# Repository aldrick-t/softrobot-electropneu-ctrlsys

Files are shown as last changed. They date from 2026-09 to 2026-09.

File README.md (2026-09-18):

# softrobot-electropneu-ctrlsys
Control elements for pneumatic actuated soft robots. Including microcontroller controller firmware, controller PCBs, control board use guidelines and more.

## Closed-loop vacuum controller

This PlatformIO firmware regulates a negative-pressure pneumatic circuit with
an ESP32 DevKit V1, a vacuum-pump motor, a solenoid valve, an ADS1115 ADC, and
a 5 V XGZP6847A pressure sensor. It is set up for the installed
`XGZP6847A100KPGPN` variant: its nominal 0.5–4.5 V output represents −100 to
+100 kPa gauge pressure. The controller only commands negative pressure.

### Hardware and signal path

| Function | Connection | Firmware behavior |
| --- | --- | --- |
| Pump motor PWM | ESP32 GPIO 2 | `0` is off; `255` is full duty cycle. |
| Solenoid valve | ESP32 GPIO 5 | HIGH opens the pump-to-gripper path; LOW de-energizes the valve and vents the gripper. |
| Target-reached LED1 (green) | ESP32 GPIO 12 through 220 Ω to GND | On only when serial closed-loop pressure is within the configured deadband. |
| Active LED2 | ESP32 GPIO 13 through 220 Ω to GND | On when firmware commands nonzero pump PWM or energizes the valve. |
| Mode switch: manual full | ESP32 GPIO 26 with 1 kΩ pulldown | 3.3 V selects pump PWM `255` and valve open. |
| Mode switch: serial control | ESP32 GPIO 27 with 1 kΩ pulldown | 3.3 V enables serial closed-loop control. |
| ADS1115 SDA | ESP32 GPIO 21 through the 3.3 V/5 V I2C level shifter | Initialized with `Wire.begin(21, 22)`. |
| ADS1115 SCL | ESP32 GPIO 22 through the 3.3 V/5 V I2C level shifter | Initialized with `Wire.begin(21, 22)`. |
| XGZP6847A output | ADS1115 A0 | Read as a 5 V-domain analog signal; it never connects directly to the ESP32. |

The ADC uses its ±6.144 V range (`GAIN_TWOTHIRDS`), so the sensor's 0.5–4.5 V
signal cannot clip. After field zeroing, the nominal conversion is:

```text
pressure_kPa = 50 × (sensor_volts − zero_volts)
```

`ZERO` removes the atmospheric offset; it does not replace a calibrated span
check against a reference gauge.

## Operation

With the pressure port open to atmosphere, first send:

```text
ZERO
```

The controller turns both outputs off for one second, then averages 32 stable
pressure samples. Do not obstruct the vent or run the pump while it calibrates.

After `ZERO complete`, send a negative gauge-pressure target as a bare number:

```text
-20
-65.93
```

The accepted range is −90 to 0 kPa. Values below −90 kPa clamp to −90; positive
values clamp to zero and vent. Any zero representation stops control and vents:

```text
0
0.0
-0.0
```

### Serial commands

| Command | Effect |
| --- | --- |
| `ZERO` | In serial mode, vent, establish atmospheric offset, and permit negative targets. Required after every reboot. |
| `STATUS` | Print controller state, mode, voltage, pressure, target, PWM, valve state, LED states, ADC address, calibration state, and tuning. |
| `STATUS_STREAM` | Toggle continuous `STATUS` output at 20 Hz. Send `STATUS_STREAM` again to stop it. |
| `KP <value>` | Set proportional gain in RAM; allowed range 0–50. |
| `KI <value>` | Set integral gain in RAM; allowed range 0–20. |
| `KD <value>` | Set derivative damping gain in RAM; allowed range 0–10. |
| `BAND <kPa>` | Set deadband in RAM; allowed range 0.1–5 kPa. |
| `SAVE` | Persist current validated tuning in ESP32 Preferences. |
| `DEFAULTS` | Restore conservative default tuning in RAM; send `SAVE` to retain it after reboot. |

Malformed commands stop active control and vent as a precaution.

## Controller behavior

The loop runs every 50 ms and averages four ADS1115 readings per update. PID
control uses anti-windup, a filtered pressure-rate term, and a PWM slew limit.

- If pressure is not negative enough, the valve opens to the pump and PWM rises
  gradually.
- At or beyond the target deadband, the pump turns off while the valve remains
  on the pump-to-gripper path. The controller does not use the full-flow
  atmosphere vent as a corrective actuator.
- Passive venting (valve off) remains the safety/release path for `0`, faults,
  malformed commands, and `ZERO`.

This checkout's defaults are `KP=18`, `KI=1`, `KD=0.3`, and `BAND=0.5 kPa`.
Tune them on the real pump, tubing volume, valve flow, and gripper before
relying on them. In particular, confirm that valve-on/pump-off holds vacuum
without overheating a non-continuous-duty valve coil.

### Switch modes and LEDs

The SPDT mode switch is the output authority. The firmware reads both switch
inputs on every loop and accepts only these complementary states:

| GPIO 26 | GPIO 27 | Mode | Output behavior |
| --- | --- | --- | --- |
| HIGH | LOW | Manual full-drive | Pump PWM is `255` and the valve is energized, even if the ADS1115 is unavailable or faulted. Entering this mode cancels any serial target or calibration in progress. LED2 is on; LED1 is off. |
| LOW | HIGH | Serial closed-loop | The controller remains vented/idle until a new negative serial target is sent. Existing ADC, `ZERO`, target-range, and fault checks apply. |
| LOW | LOW | Safe off | Pump and valve are de-energized. |
| HIGH | HIGH | Safe off | Pump and valve are de-energized. |

Returning from manual full-drive to serial mode does not restore an earlier
target; send `ZERO` if needed, then a new negative target. In manual or
safe-off mode, `ZERO` and numeric target commands are rejected. `STATUS`,
tuning commands, `SAVE`, and `DEFAULTS` remain available.

LED1 is off while the controller ramps, vents, settles, calibrates, idles, is
faulted, or is in manual/safe-off mode. LED2 represents **commanded drive**:
it cannot prove that a disconnected, stalled, or failed motor/valve is drawing
current because this board has no current-sense circuit.

### ADS1115 ADDR override

For reliable normal operation, wire ADS1115 `ADDR` to GND and use I2C address
`0x48`. The ADS1115 samples this address-selection pin continuously, so a
floating pin is not dependable.

For initial bench testing, `src/main.cpp` includes:

```cpp
const bool ALLOW_FLOATING_ADS1115_ADDR_FOR_TESTING = true;
```

With this temporary toggle enabled, firmware first tries `0x48`, then the
other legal ADS1115 addresses (`0x49`, `0x4A`, `0x4B`). It prints a warning if
the ADC is found away from `0x48`; `STATUS` also reports `ADS_ADDR`. This only
accommodates an accidentally stable floating pin. After wiring `ADDR → GND`,
set this toggle to `false` and rebuild.

## Installation and upload

1. Install [PlatformIO for VS Code](https://platformio.org/install/ide?install=vscode)
   and open this repository as a PlatformIO project.
2. Confirm `platformio.ini` targets `esp32doit-devkit-v1`.
3. Build. PlatformIO installs `Adafruit ADS1X15` automatically; `Arduino`,
   `Wire`, and ESP32 `Preferences` are framework libraries.

   ```sh
   pio run
   ```

4. Connect the ESP32 by USB and upload:

   ```sh
   pio run --target upload
   ```

5. Open a serial monitor at **115200 baud** with line ending set to `Newline`:

   ```sh
   pio device monitor --baud 115200
   ```

Boot starts deliberately uncalibrated. The firmware leaves the pump and valve
off and rejects negative targets until `ZERO` succeeds.

## Idle, off, and fault behavior

The firmware commands **both motor and valve off electrically** when it
is idle or at atmospheric pressure:

```cpp
setOutputs(PWM_OFF, false);
// pump:  analogWrite(GPIO 2, 0)
// valve: analogWrite(GPIO 5, 0)
```

This output path is used at boot, after `0`, after a positive target clamps to
zero, after malformed input, during zeroing, on pressure/ADC faults, and for
invalid mode-switch states. The D26 manual-full mode is the explicit exception:
it deliberately drives both outputs even with a sensor fault. With the stated
plumbing, valve-off is also the pneumatic vent state; it does not attempt to
hold vacuum. Therefore the valve coil is not intentionally kept energized while
idle, avoiding prolonged activation and overheating.

This conclusion assumes a non-inverting valve driver where GPIO 5 HIGH
energizes the coil, as defined by the original controller. Confirm that once
with a multimeter or indicator LED before connecting a gripper.

## First physical test

1. Test with the gripper disconnected or a conservative vented fixture.
2. Select serial mode (GPIO 27 HIGH) and send `STATUS`; verify `MODE=SERIAL`,
   `PWM=0`, `VALVE=VENT`, `LED1=OFF`, `LED2=OFF`, and `ZERO=REQUIRED`.
3. Run `ZERO` with the port open to atmosphere. If possible, compare reported
   voltage with a multimeter at ADS1115 A0.
4. Start with `-5`, then `-10`; verify motor PWM ramps rather than jumps,
   LED2 is on while the pump or valve is commanded, and LED1 turns on only
   after pressure reaches the configured deadband.
5. Send `0` and verify both PWM outputs and both LEDs are off before longer tests.
6. Select manual full-drive (GPIO 26 HIGH) and verify `PWM=255`, `VALVE=OPEN`,
   LED2 on, and LED1 off. Return to serial mode and verify it remains vented
   until a new negative target is sent.
7. Verify both-low and both-high switch input states keep both outputs and LEDs off.
8. Tune one variable at a time and send `SAVE` only after physical validation.

Never treat the −90 kPa software clamp as proof that the gripper, tubing,
fittings, or pump are safe at that pressure.

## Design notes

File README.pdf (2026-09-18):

# softrobot-electropneu-ctrlsys

Control elements for pneumatic actuated soft robots. Including microcontroller controller firmware, controller PCBs, control board use guidelines and more.

## Closed-loop vacuum controller

This PlatformIO firmware regulates a negative-pressure pneumatic circuit with an ESP32 DevKit V1, a vacuum-pump motor, a solenoid valve, an ADS1115 ADC, and a 5 V XGZP6847A pressure sensor. It is set up for the installed XGZP6847A100KPGPN variant: its nominal 0.5–4.5 V output represents −100 to +100 kPa gauge pressure. The controller only commands negative pressure.

Hardware and signal path

Function | Connection | Firmware behavior
Pump motor PWM | ESP32 GPIO 2 | 0 is off; 255 is full duty cycle.
Solenoid valve | ESP32 GPIO 5 | HIGH opens the pump-to-gripper path; LOW de-energizes the valve and vents the gripper.
Target-reached LED1 (green) | ESP32 GPIO 12 through 220 Ω to GND | On only when serial closed-loop pressure is within the configured deadband.
Active LED2 | ESP32 GPIO 13 through 220 Ω to GND | On when firmware commands nonzero pump PWM or energizes the valve.
Mode switch: manual full | ESP32 GPIO 26 with 1 kΩ pulldown | 3.3 V selects pump PWM 255 and valve open.
Mode switch: serial control | ESP32 GPIO 27 with 1 kΩ pulldown | 3.3 V enables serial closed-loop control.

ADS1115 SDA

ESP32 GPIO 21 through the
3.3 V/5 V I2C level shifter

Initialized with Wire.begin(21, 22).

ADS1115 SCL

ESP32 GPIO 22 through the
3.3 V/5 V I2C level shifter

Initialized with Wire.begin(21, 22).

XGZP6847A
output

ADS1115 A0

Read as a 5 V-domain analog signal; it never connects directly to the ESP32.

The ADC uses its ±6.144 V range (GAIN_TWOTHIRDS), so the sensor's 0.5–4.5 V signal cannot clip. After field zeroing, the nominal conversion is:

pressure_kPa = 50 × (sensor_volts − zero_volts)

ZERO removes the atmospheric offset; it does not replace a calibrated span check against a reference gauge.

README.md | 2026-09-18

ADS1115 ADDR: temporary test override

For reliable normal operation, wire ADS1115 ADDR to GND and use I2C address 0x48. The ADS1115 samples this address-selection pin continuously, so a floating pin is not dependable.

For initial bench testing, src/main.cpp includes:

With this temporary toggle enabled, firmware first tries 0x48, then the other legal ADS1115 addresses (0x49, 0x4A, 0x4B). It prints a warning if the ADC is found away from 0x48; STATUS also reports ADS_ADDR. This only accommodates an accidentally stable floating pin. After wiring ADDR → GND, set this toggle to false and rebuild.

## Installation and upload

1. Install PlatformIO for VS Code (https://platformio.org/install/ide?install=vscode) and open this repository as a PlatformIO project.
2. Confirm platformio.ini targets esp32doit-devkit-v1.
3. Build. PlatformIO installs Adafruit ADS1X15 automatically; Arduino, Wire, and ESP32
4. Connect the ESP32 by USB and upload:
5. Open a serial monitor at 115200 baud with line ending set to Newline:

Boot starts deliberately uncalibrated. The firmware leaves the pump and valve off and rejects negative targets until ZERO succeeds.

Switch modes and LEDs

The SPDT mode switch is the output authority. The firmware reads both switch inputs on every loop and accepts only these complementary states:

GPIO
26

GPIO
27
Mode | Output behavior
HIGH | LOW

Manual
full-drive

Pump PWM is 255 and the valve is energized, even if the ADS1115 is unavailable or faulted. Entering this mode cancels any serial target or calibration in progress. LED2 is on; LED1 is off.

LOW | HIGH | Serial closed- loop | The controller remains vented/idle until a new negative serial target is sent. Existing ADC, ZERO, target-range, and fault checks apply.
LOW | LOW | Safe off | Pump and valve are de-energized.
HIGH | HIGH | Safe off | Pump and valve are de-energized.

Returning from manual full-drive to serial mode does not restore an earlier target; send ZERO if needed, then a new negative target. In manual or safe-off mode, ZERO and numeric target commands are rejected. STATUS, tuning commands, SAVE, and DEFAULTS remain available.

LED1 is off while the controller ramps, vents, settles, calibrates, idles, is faulted, or is in manual/safe-off mode. LED2 represents commanded drive: it cannot prove that a disconnected, stalled, or failed motor/valve is drawing current because this board has no current-sense circuit.

## Operation

With the pressure port open to atmosphere, first send:

The controller turns both outputs off for one second, then averages 32 stable pressure samples. Do not obstruct the vent or run the pump while it calibrates.

After ZERO complete, send a negative gauge-pressure target as a bare number:

The accepted range is −90 to 0 kPa. Values below −90 kPa clamp to −90; positive values clamp to zero and vent. Any zero representation stops control and vents:

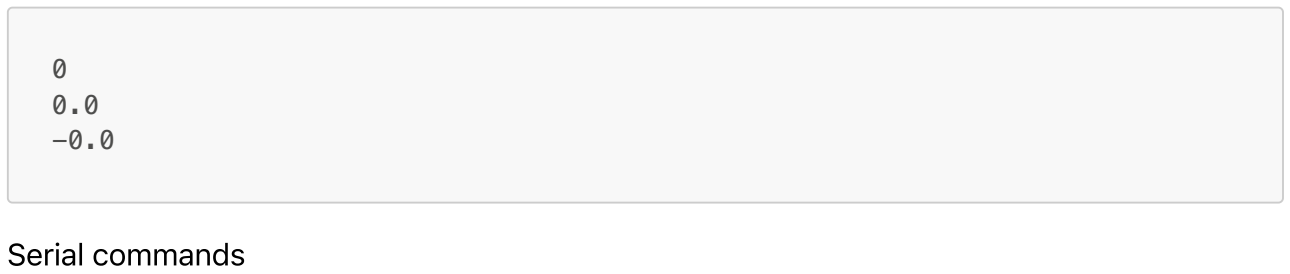
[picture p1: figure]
Serial commands

Command | Effect
ZERO | In serial mode, vent, establish atmospheric offset, and permit negative targets. Required after every reboot.
STATUS | Print controller state, mode, voltage, pressure, target, PWM, valve state, LED states, ADC address, calibration state, and tuning.
STATUS_STREAM | Toggle continuous STATUS output at 20 Hz. Send STATUS_STREAM again to stop it.
KP <value> | Set proportional gain in RAM; allowed range 0–50.
KI <value> | Set integral gain in RAM; allowed range 0–20.
KD <value> | Set derivative damping gain in RAM; allowed range 0–10.
BAND <kPa> | Set deadband in RAM; allowed range 0.1–5 kPa.
SAVE | Persist current validated tuning in ESP32 Preferences.
DEFAULTS | Restore conservative default tuning in RAM; send SAVE to retain it after reboot.

Malformed commands stop active control and vent as a precaution.

## Controller behavior

The loop runs every 50 ms and averages four ADS1115 readings per update. PID control uses antiwindup, a filtered pressure-rate term, and a PWM slew limit.

If pressure is not negative enough, the valve opens to the pump and PWM rises gradually.
At or beyond the target deadband, the pump turns off while the valve remains on the pump-togripper path. The controller does not use the full-flow atmosphere vent as a corrective actuator. Passive venting (valve off) remains the safety/release path for 0, faults, malformed commands, and ZERO.

This checkout's defaults are KP=18, KI=1, KD=0.3, and BAND=0.5 kPa. Tune them on the real pump, tubing volume, valve flow, and gripper before relying on them. In particular, confirm that valve-on/pumpoff holds vacuum without overheating a non-continuous-duty valve coil.

## Idle, off, and fault behavior

Yes: the firmware commands both motor and valve off electrically when it is idle or at atmospheric

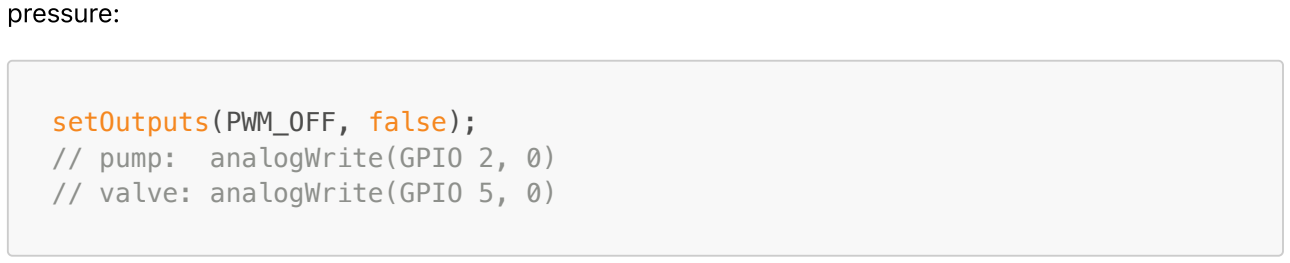
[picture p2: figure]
pressure:; setOutputs(PWM_OFF, false); // pump: analogWrite(GPIO 2, 0) // valve: analogWrite(GPIO 5, 0)

This output path is used at boot, after 0, after a positive target clamps to zero, after malformed input, during zeroing, on pressure/ADC faults, and for invalid mode-switch states. The D26 manual-full mode is the explicit exception: it deliberately drives both outputs even with a sensor fault. With the stated plumbing, valve-off is also the pneumatic vent state; it does not attempt to hold vacuum. Therefore the valve coil is not intentionally kept energized while idle, avoiding prolonged activation and overheating.

This conclusion assumes a non-inverting valve driver where GPIO 5 HIGH energizes the coil, as defined by the original controller. Confirm that once with a multimeter or indicator LED before connecting a gripper.

## First physical test

1. Test with the gripper disconnected or a conservative vented fixture.
2. Select serial mode (GPIO 27 HIGH) and send STATUS; verify MODE=SERIAL, PWM=0, VALVE=VENT, LED1=OFF, LED2=OFF, and ZERO=REQUIRED.
3. Run ZERO with the port open to atmosphere. If possible, compare reported voltage with a multimeter at ADS1115 A0.
4. Start with -5, then -10; verify motor PWM ramps rather than jumps, LED2 is on while the pump or valve is commanded, and LED1 turns on only after pressure reaches the configured deadband.
5. Send 0 and verify both PWM outputs and both LEDs are off before longer tests.
6. Select manual full-drive (GPIO 26 HIGH) and verify PWM=255, VALVE=OPEN, LED2 on, and LED1 off. Return to serial mode and verify it remains vented until a new negative target is sent.
7. Verify both-low and both-high switch input states keep both outputs and LEDs off.
8. Tune one variable at a time and send SAVE only after physical validation.

Never treat the −90 kPa software clamp as proof that the gripper, tubing, fittings, or pump are safe at that pressure.

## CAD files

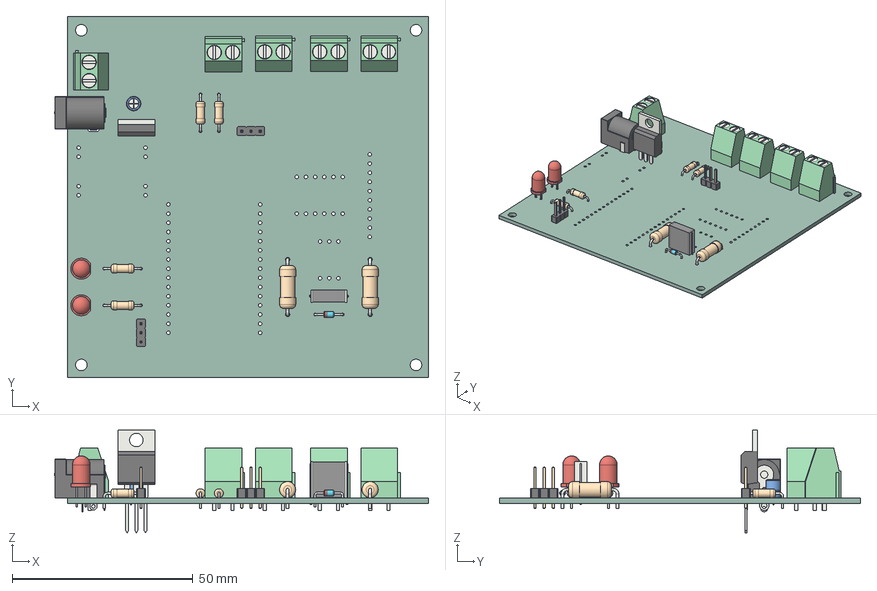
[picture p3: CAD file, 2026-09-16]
electropneu/electropneu.step
103.6 x 100.0 x 28.5 mm
LED_D5.0mm x 2
TerminalBlock_Phoenix_MKDS-1,5-2-5.08_1x02_P5.08mm_Horizontal x 5
C_Radial_D4.0mm_H5.0mm_P1.50mm
R_Axial_DIN0414_L11.9mm_D4.5mm_P15.24mm_Horizontal x 2
D_DO-34_SOD68_P7.62mm_Horizontal
BarrelJack_Horizontal
PinHeader_1x03_P2.54mm_Vertical x 2
TO-220-3_Vertical
R_Axial_DIN0207_L6.3mm_D2.5mm_P10.16mm_Horizontal x 4
C_Rect_L11.0mm_W3.4mm_P10.00mm_MKT
electropneu_PCB

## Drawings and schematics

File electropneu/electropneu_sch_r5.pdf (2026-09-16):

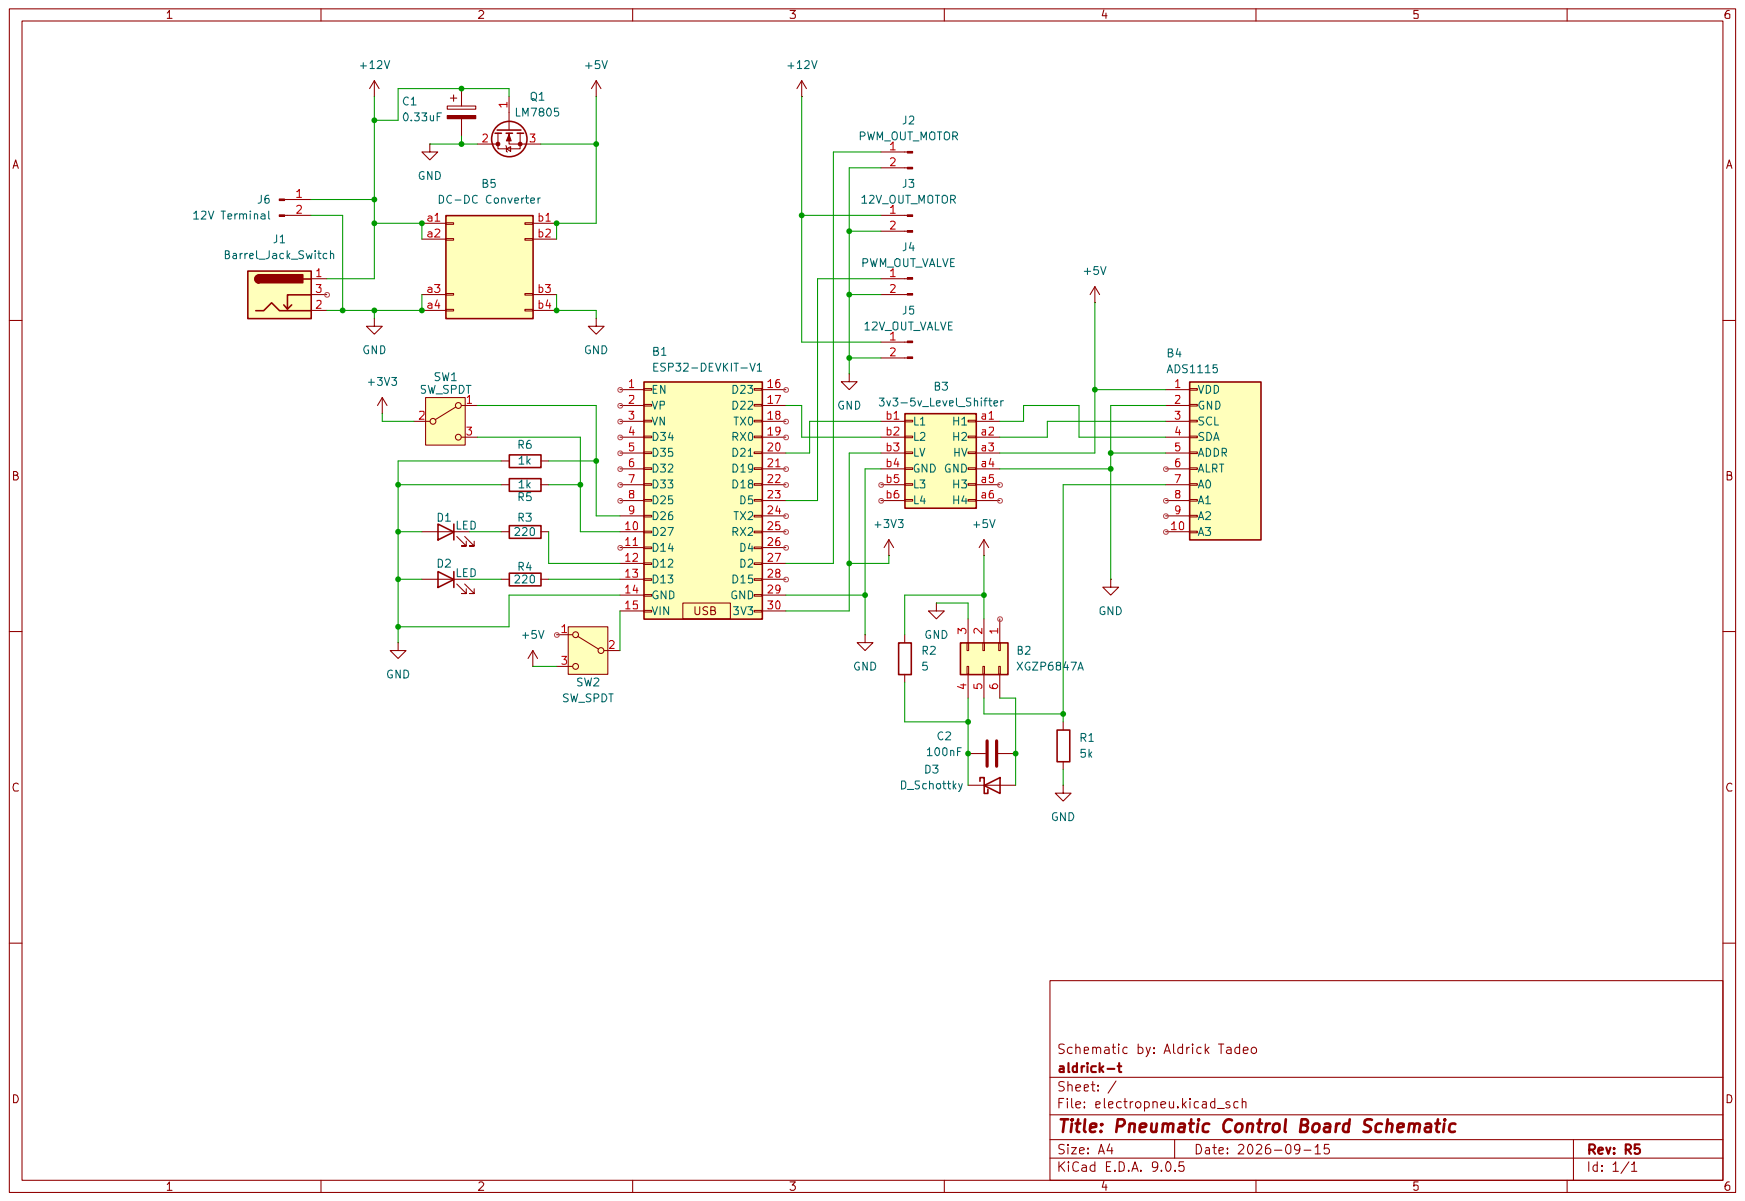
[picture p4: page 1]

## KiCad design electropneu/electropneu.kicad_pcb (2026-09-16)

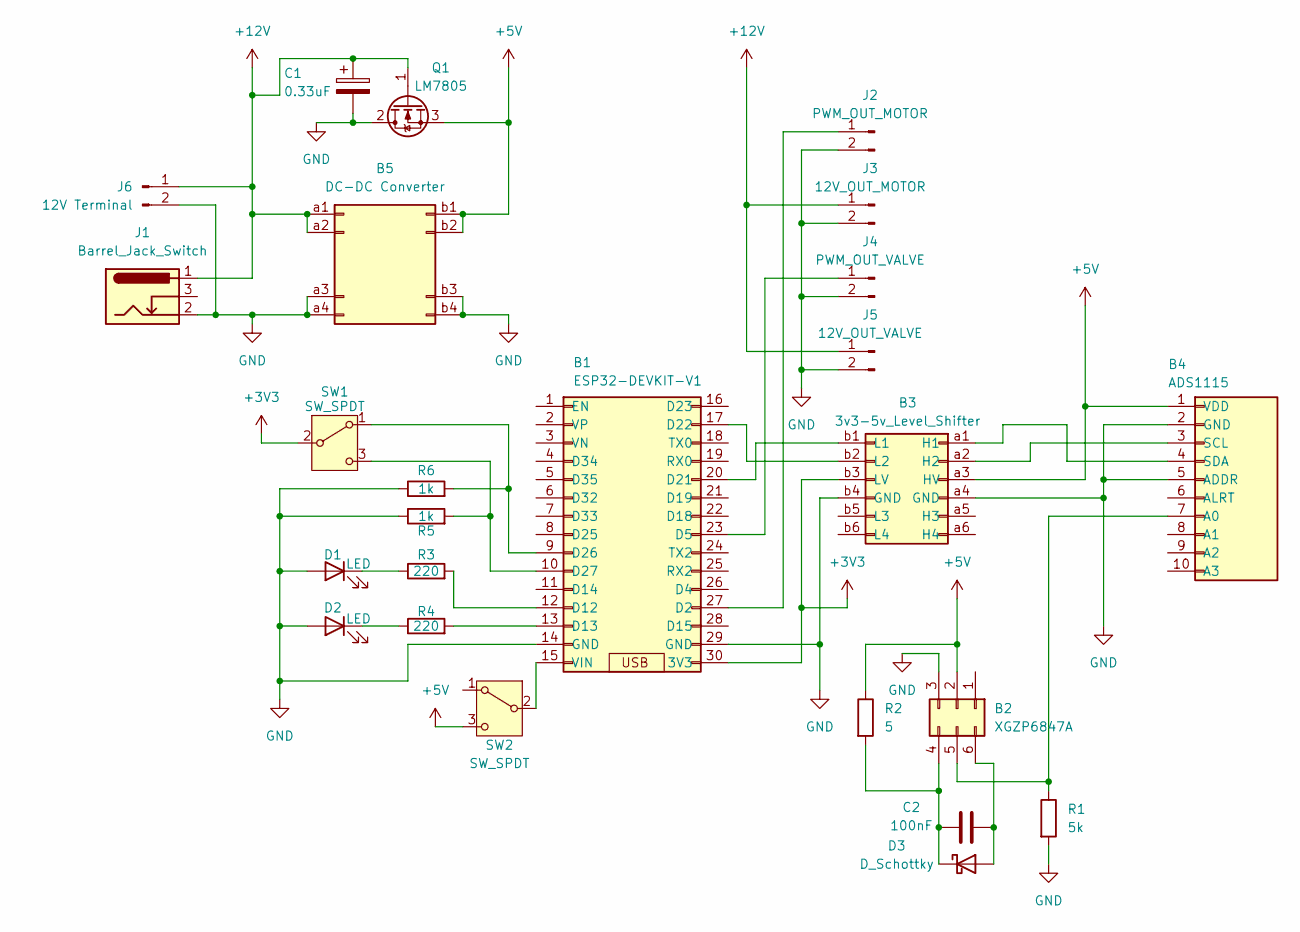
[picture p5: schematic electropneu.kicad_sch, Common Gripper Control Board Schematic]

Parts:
B1: ESP32-DEVKIT-V1
B2: XGZP6847A; XGZP6847A Sensor Board
B3: 3v3-5v_Level_Shifter; LevelShifter_3V3-5V
B4: ADS1115; ADS1115 Board
B5: DC-DC Converter; MP1584EN Board
C1: 0.33uF; C_Radial_D4.0mm_H5.0mm_P1.50mm
C2: 100nF; C_Rect_L11.0mm_W3.4mm_P10.00mm_MKT
D1, D2: LED; LED_D5.0mm
D3: D_Schottky; D_DO-34_SOD68_P7.62mm_Horizontal
J1: Barrel_Jack_Switch; BarrelJack_Horizontal
J2: PWM_OUT_MOTOR; TerminalBlock_Phoenix_MKDS-1,5-2-5.08_1x02_P5.08mm_Horizont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
J3: 12V_OUT_MOTOR; TerminalBlock_Phoenix_MKDS-1,5-2-5.08_1x02_P5.08mm_Horizont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
J4: PWM_OUT_VALVE; TerminalBlock_Phoenix_MKDS-1,5-2-5.08_1x02_P5.08mm_Horizont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
J5: 12V_OUT_VALVE; TerminalBlock_Phoenix_MKDS-1,5-2-5.08_1x02_P5.08mm_Horizont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
J6: 12V Terminal; TerminalBlock_Phoenix_MKDS-1,5-2-5.08_1x02_P5.08mm_Horizont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
Q1: LM7805; TO-220-3_Vertical
R1: 5k; R_Axial_DIN0414_L11.9mm_D4.5mm_P15.24mm_Horizontal
R2: 5; R_Axial_DIN0414_L11.9mm_D4.5mm_P15.24mm_Horizontal
R3, R4: 220; R_Axial_DIN0207_L6.3mm_D2.5mm_P10.16mm_Horizontal
R5, R6: 1k; R_Axial_DIN0207_L6.3mm_D2.5mm_P10.16mm_Horizontal
SW1, SW2: SW_SPDT; PinHeader_1x03_P2.54mm_Vertical

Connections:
+3V3: B1.30 (3V3), B3.b3 (LV), SW1.2 (B)
+5V: B2.2, B3.a3 (HV), B4.1 (VDD), B5.b1, B5.b2, Q1.3 (S), R2.1, SW2.3 (C)
+12V: B5.a1, B5.a2, C1.1, J1.1, J3.1, J5.1, J6.1, Q1.1 (G)
GND: B1.14 (GND), B1.29 (GND), B2.3, B3.a4 (GND), B3.b4 (GND), B4.2 (GND), B4.5 (ADDR), B5.a3, B5.a4, B5.b3, B5.b4, C1.2, D1.2 (A), D2.2 (A), J1.2, J2.2, J3.2, J4.2, J5.2, J6.2, Q1.2 (D), R1.2, R5.1, R6.1
unnamed: B1.27 (D2), J2.1
unnamed: B1.23 (D5), J4.1
unnamed: B1.12 (D12), R3.2
unnamed: B1.13 (D13), R4.2
unnamed: B1.20 (D21), B3.b1 (L1)
unnamed: B1.17 (D22), B3.b2 (L2)
unnamed: B1.9 (D26), R6.2, SW1.1 (A)
unnamed: B1.10 (D27), R5.2, SW1.3 (C)
unnamed: B1.15 (VIN), SW2.2 (B)
unnamed: B2.4, C2.1, D3.1 (K), R2.2
unnamed: B2.5, B4.7 (A0), R1.1
unnamed: B2.6, C2.2, D3.2 (A)
unnamed: B3.a1 (H1), B4.4 (SDA)
unnamed: B3.a2 (H2), B4.3 (SCL)
unnamed: D1.1 (K), R3.1
unnamed: D2.1 (K), R4.1

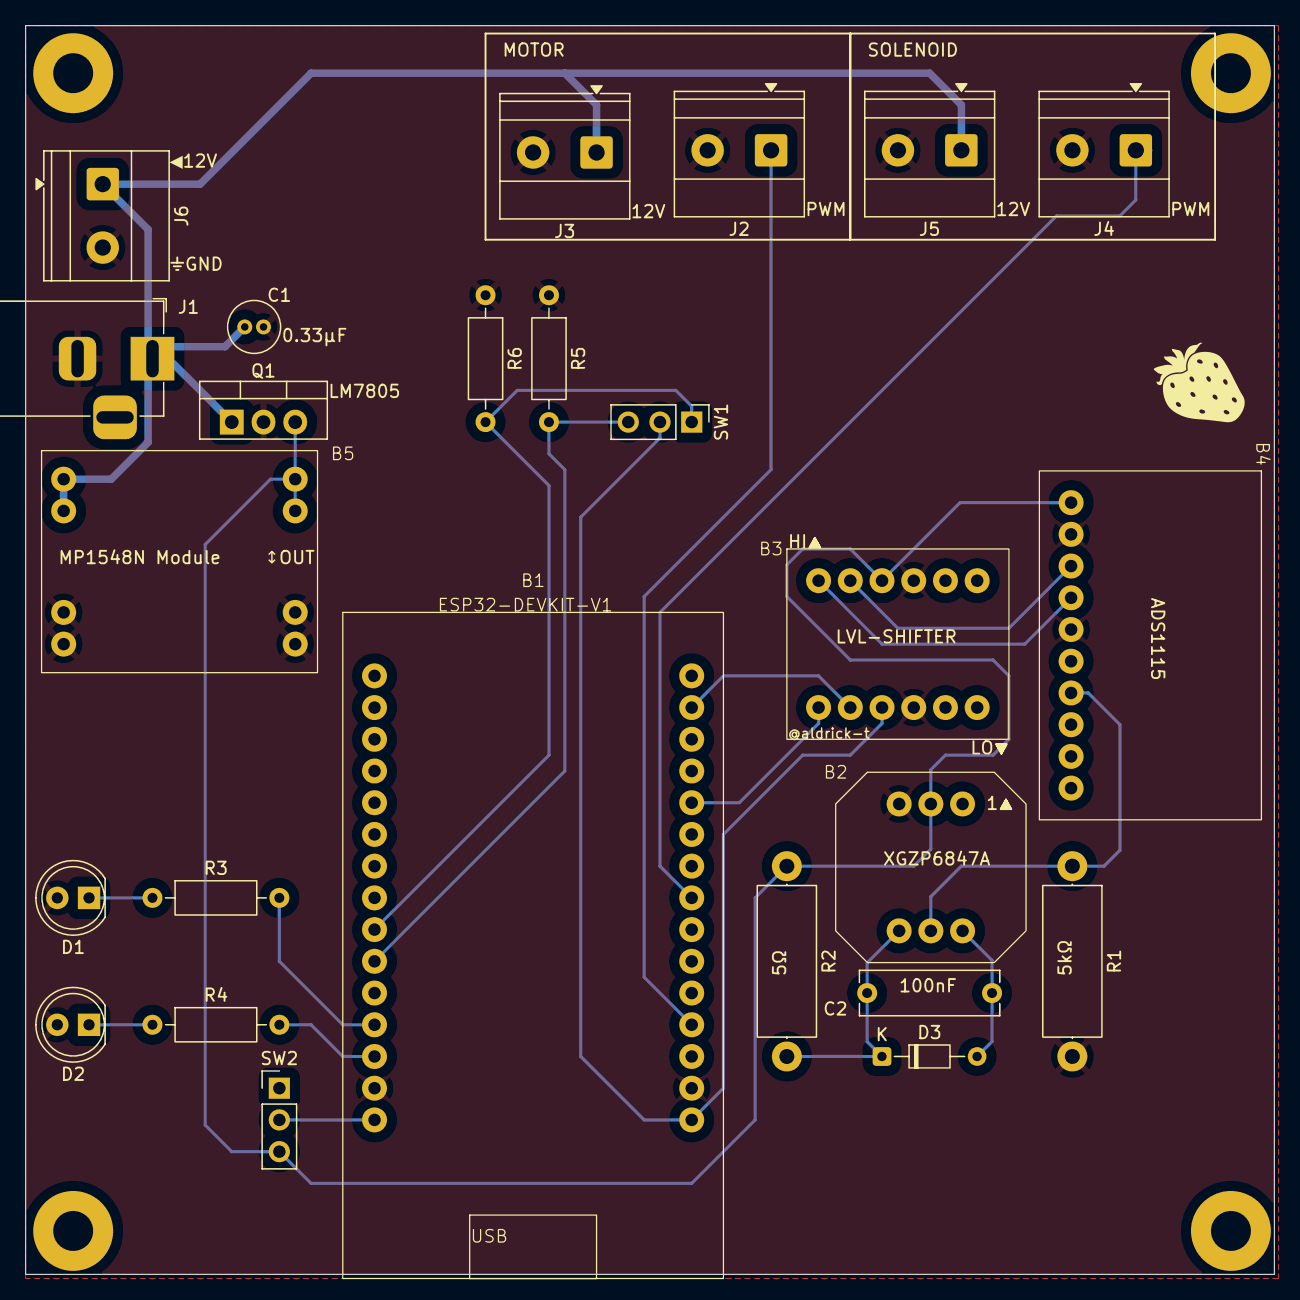
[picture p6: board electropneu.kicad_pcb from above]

Board: 2 copper layers, 100.0 x 100.0 mm, 25 parts (0 on the bottom side), 20 nets.

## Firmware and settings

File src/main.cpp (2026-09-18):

#include <Arduino.h>
#include <Adafruit_ADS1X15.h>
#include <Preferences.h>
#include <Wire.h>

#include <math.h>
#include <stdlib.h>
#include <string.h>

// Board connections retained from the original on/off controller.
const uint8_t PIN_PWM_PUMP = 2;
const uint8_t PIN_PWM_VALVE = 5;
const uint8_t PIN_LED_TARGET_REACHED = 12;
const uint8_t PIN_LED_ACTIVE = 13;
const uint8_t PIN_I2C_SDA = 21;
const uint8_t PIN_I2C_SCL = 22;
const uint8_t PIN_SWITCH_MANUAL_FULL = 26;
const uint8_t PIN_SWITCH_SERIAL = 27;

const uint8_t ADS1115_GND_ADDRESS = 0x48;
// Temporary bench-test override only. When true, the firmware falls back to the
// other legal ADS1115 addresses if a floating ADDR pin does not answer at 0x48.
// Set false after wiring ADDR to GND for normal operation.
const bool ALLOW_FLOATING_ADS1115_ADDR_FOR_TESTING = true;
const uint8_t ADS1115_CHANNEL = 0;

const uint32_t CONTROL_PERIOD_MS = 50;
const uint32_t STATUS_STREAM_PERIOD_MS = CONTROL_PERIOD_MS;
const uint32_t ZERO_SETTLE_MS = 1000;
const uint8_t ZERO_SAMPLE_COUNT = 32;
const uint8_t ADC_AVERAGE_COUNT = 4;
const float ZERO_MAX_STDDEV_KPA = 0.10f;

const float SENSOR_KPA_PER_VOLT = 50.0f;  // 100KPGPN: -100..100 kPa over 0.5..4.5 V.
const float MAX_VACUUM_TARGET_KPA = -90.0f;
const float ADC_MIN_VALID_VOLTS = 0.25f;
const float ADC_MAX_VALID_VOLTS = 4.75f;
const uint8_t MAX_INVALID_READINGS = 3;

const uint8_t PWM_OFF = 0;
const uint8_t PWM_MAX = 255;
const uint8_t PWM_SLEW_PER_CYCLE = 10;
const float DERIVATIVE_FILTER_ALPHA = 0.25f;

struct Tuning {
  float kp;
  float ki;
  float kd;
  float bandKpa;
};

const Tuning DEFAULT_TUNING = {6.0f, 0.0f, 0.6f, 1.0f};
const char *PREFERENCES_NAMESPACE = "vacuum-ctl";

enum class ControllerState {
  IDLE,
  CALIBRATING_SETTLE,
  CALIBRATING_SAMPLE,
  REGULATING,
  FAULT,
};

enum class ControlMode {
  SAFE_OFF,
  SERIAL_CONTROL,
  MANUAL_FULL,
};

Adafruit_ADS1115 ads;
Preferences preferences;
Tuning tuning = DEFAULT_TUNING;
ControllerState state = ControllerState::IDLE;
ControlMode controlMode = ControlMode::SAFE_OFF;

bool adsAvailable = false;
uint8_t adsAddressInUse = ADS1115_GND_ADDRESS;
bool zeroCalibrated = false;
float zeroVolts = NAN;
float measuredVolts = NAN;
float measuredPressureKpa = NAN;
float targetPressureKpa = 0.0f;
float integralTerm = 0.0f;
float previousVacuumKpa = NAN;
float filteredVacuumRate = 0.0f;
uint8_t pumpPwm = PWM_OFF;
bool valveOpen = false;
bool targetLedOn = false;
bool activeLedOn = false;
uint8_t invalidReadings = 0;
uint32_t lastControlMs = 0;
uint32_t phaseStartedMs = 0;
uint32_t lastPidMs = 0;
float zeroSum = 0.0f;
float zeroSumSquared = 0.0f;
uint8_t zeroSamples = 0;

char serialLine[96];
size_t serialLength = 0;
bool statusStreamEnabled = false;
uint32_t lastStatusStreamMs = 0;

const char *stateName(ControllerState currentState) {
  switch (currentState) {
    case ControllerState::IDLE:
      return "IDLE";
    case ControllerState::CALIBRATING_SETTLE:
      return "ZERO_SETTLE";
    case ControllerState::CALIBRATING_SAMPLE:
      return "ZERO_SAMPLE";
    case ControllerState::REGULATING:
      return "REGULATING";
    case ControllerState::FAULT:
      return "FAULT";
  }
  return "UNKNOWN";
}

const char *controlModeName(ControlMode mode) {
  switch (mode) {
    case ControlMode::SAFE_OFF:
      return "SAFE_OFF";
    case ControlMode::SERIAL_CONTROL:
      return "SERIAL";
    case ControlMode::MANUAL_FULL:
      return "MANUAL_FULL";
  }
  return "UNKNOWN";
}

bool isTargetReached() {
  return controlMode == ControlMode::SERIAL_CONTROL && state == ControllerState::REGULATING &&
         zeroCalibrated && isfinite(targetPressureKpa) && targetPressureKpa < 0.0f &&
         isfinite(measuredPressureKpa) &&
         fabsf(measuredPressureKpa - targetPressureKpa) <= tuning.bandKpa;
}

void updateIndicators() {
  targetLedOn = isTargetReached();
  activeLedOn = pumpPwm != PWM_OFF || valveOpen;
  digitalWrite(PIN_LED_TARGET_REACHED, targetLedOn ? HIGH : LOW);
  digitalWrite(PIN_LED_ACTIVE, activeLedOn ? HIGH : LOW);
}

void setOutputs(uint8_t requestedPumpPwm, bool openValve) {
  pumpPwm = requestedPumpPwm;
  valveOpen = openValve;
  analogWrite(PIN_PWM_PUMP, pumpPwm);
  analogWrite(PIN_PWM_VALVE, valveOpen ? PWM_MAX : PWM_OFF);
  updateIndicators();
}

void resetPid() {
  integralTerm = 0.0f;
  previousVacuumKpa = NAN;
  filteredVacuumRate = 0.0f;
  lastPidMs = 0;
}

void cancelSerialControl() {
  targetPressureKpa = 0.0f;
  resetPid();
  zeroSum = 0.0f;
  zeroSumSquared = 0.0f;
  zeroSamples = 0;
  if (state != ControllerState::FAULT) {
    state = ControllerState::IDLE;
  }
  updateIndicators();
}

ControlMode readControlMode() {
  const bool manualFullSelected = digitalRead(PIN_SWITCH_MANUAL_FULL) == HIGH;
  const bool serialSelected = digitalRead(PIN_SWITCH_SERIAL) == HIGH;

  if (manualFullSelected && !serialSelected) {
    return ControlMode::MANUAL_FULL;
  }
  if (!manualFullSelected && serialSelected) {
    return ControlMode::SERIAL_CONTROL;
  }
  return ControlMode::SAFE_OFF;
}

void serviceControlMode() {
  const ControlMode requestedMode = readControlMode();
  if (requestedMode != controlMode) {
    controlMode = requestedMode;
    if (controlMode == ControlMode::MANUAL_FULL || controlMode == ControlMode::SAFE_OFF) {
      cancelSerialControl();
    }

    Serial.print("MODE=");
    Serial.println(controlModeName(controlMode));
  }

  if (controlMode == ControlMode::MANUAL_FULL) {
    setOutputs(PWM_MAX, true);
  } else if (controlMode == ControlMode::SAFE_OFF) {
    setOutputs(PWM_OFF, false);
  }
}

void stopAndVent(const char *message) {
  targetPressureKpa = 0.0f;
  resetPid();
  state = ControllerState::IDLE;
  setOutputs(PWM_OFF, false);
  if (message != nullptr) {
    Serial.println(message);
  }
}

void enterFault(const char *message) {
  targetPressureKpa = 0.0f;
  zeroCalibrated = false;
  resetPid();
  state = ControllerState::FAULT;
  setOutputs(PWM_OFF, false);
  Serial.print("FAULT: ");
  Serial.println(message);
}

bool tuningIsValid(const Tuning &candidate) {
  return isfinite(candidate.kp) && candidate.kp >= 0.0f && candidate.kp <= 50.0f &&
         isfinite(candidate.ki) && candidate.ki >= 0.0f && candidate.ki <= 20.0f &&
         isfinite(candidate.kd) && candidate.kd >= 0.0f && candidate.kd <= 10.0f &&
         isfinite(candidate.bandKpa) && candidate.bandKpa >= 0.1f && candidate.bandKpa <= 5.0f;
}

void loadTuning() {
  Tuning loaded = DEFAULT_TUNING;
  if (preferences.begin(PREFERENCES_NAMESPACE, true)) {
    if (preferences.isKey("kp")) {
      loaded.kp = preferences.getFloat("kp", DEFAULT_TUNING.kp);
      loaded.ki = preferences.getFloat("ki", DEFAULT_TUNING.ki);
      loaded.kd = preferences.getFloat("kd", DEFAULT_TUNING.kd);
      loaded.bandKpa = preferences.getFloat("band", DEFAULT_TUNING.bandKpa);
    }
    preferences.end();
  }

  tuning = tuningIsValid(loaded) ? loaded : DEFAULT_TUNING;
}

bool saveTuning() {
  if (!tuningIsValid(tuning) || !preferences.begin(PREFERENCES_NAMESPACE, false)) {
    return false;
  }

  const bool saved = preferences.putFloat("kp", tuning.kp) > 0 &&
                     preferences.putFloat("ki", tuning.ki) > 0 &&
                     preferences.putFloat("kd", tuning.kd) > 0 &&
                     preferences.putFloat("band", tuning.bandKpa) > 0;
  preferences.end();
  return saved;
}

bool readAveragedVoltage(float &volts) {
  int32_t total = 0;
  for (uint8_t sample = 0; sample < ADC_AVERAGE_COUNT; ++sample) {
    total += ads.readADC_SingleEnded(ADS1115_CHANNEL);
  }

  // ADS1115 GAIN_TWOTHIRDS has a 0.1875 mV least-significant bit.
  volts = (static_cast<float>(total) / ADC_AVERAGE_COUNT) * 0.0001875f;
  return isfinite(volts);
}

bool initializeAds1115() {
  if (ads.begin(ADS1115_GND_ADDRESS, &Wire)) {
    adsAddressInUse = ADS1115_GND_ADDRESS;
    return true;
  }

  if (!ALLOW_FLOATING_ADS1115_ADDR_FOR_TESTING) {
    return false;
  }

  const uint8_t fallbackAddresses[] = {0x49, 0x4A, 0x4B};
  for (const uint8_t address : fallbackAddresses) {
    if (ads.begin(address, &Wire)) {
      adsAddressInUse = address;
      return true;
    }
  }
  return false;
}

void reportStatus() {
  Serial.print("STATE=");
  Serial.print(stateName(state));
  Serial.print(" MODE=");
  Serial.print(controlModeName(controlMode));
  Serial.print(" V=");
  if (isfinite(measuredVolts)) {
    Serial.print(measuredVolts, 4);
  } else {
    Serial.print("NA");
  }
  Serial.print(" P_kPa=");
  if (isfinite(measuredPressureKpa)) {
    Serial.print(measuredPressureKpa, 2);
  } else {
    Serial.print("NA");
  }
  Serial.print(" TARGET=");
  Serial.print(targetPressureKpa, 2);
  Serial.print(" PWM=");
  Serial.print(pumpPwm);
  Serial.print(" VALVE=");
  Serial.print(valveOpen ? "OPEN" : "VENT");
  Serial.print(" LED1=");
  Serial.print(targetLedOn ? "ON" : "OFF");
  Serial.print(" LED2=");
  Serial.print(activeLedOn ? "ON" : "OFF");
  Serial.print(" ZERO=");
  Serial.print(zeroCalibrated ? "OK" : "REQUIRED");
  Serial.print(" KP=");
  Serial.print(tuning.kp, 3);
  Serial.print(" KI=");
  Serial.print(tuning.ki, 3);
  Serial.print(" KD=");
  Serial.print(tuning.kd, 3);
  Serial.print(" BAND=");
  Serial.print(tuning.bandKpa, 2);
  Serial.print(" ADS_ADDR=0x");
  Serial.println(adsAddressInUse, HEX);
}

void startZeroCalibration() {
  if (controlMode != ControlMode::SERIAL_CONTROL) {
    Serial.println("ERROR: ZERO is available only in SERIAL mode");
    return;
  }

  if (!adsAvailable || state == ControllerState::FAULT) {
    Serial.println("ERROR: ADS1115 unavailable; cannot ZERO");
    return;
  }

  targetPressureKpa = 0.0f;
  zeroCalibrated = false;
  resetPid();
  zeroSum = 0.0f;
  zeroSumSquared = 0.0f;
  zeroSamples = 0;
  state = ControllerState::CALIBRATING_SETTLE;
  phaseStartedMs = millis();
  setOutputs(PWM_OFF, false);
  Serial.println("ZERO: venting for 1000 ms; keep the pressure port at atmosphere");
}

void setTarget(float requestedTargetKpa) {
  if (controlMode != ControlMode::SERIAL_CONTROL) {
    Serial.println("ERROR: targets are available only in SERIAL mode");
    return;
  }

  if (!isfinite(requestedTargetKpa)) {
    stopAndVent("ERROR: target must be a finite number; venting");
    return;
  }

  if (state == ControllerState::FAULT) {
    Serial.println("ERROR: controller fault; reboot after correcting hardware");
    return;
  }

  if (requestedTargetKpa >= 0.0f) {
    stopAndVent(requestedTargetKpa > 0.0f ? "TARGET clamped to 0.00 kPa; venting" : "OFF: venting");
    return;
  }

  if (!zeroCalibrated) {
    stopAndVent("ERROR: run ZERO at atmosphere before a negative target; venting");
    return;
  }

  targetPressureKpa = requestedTargetKpa;
  if (targetPressureKpa < MAX_VACUUM_TARGET_KPA) {
    targetPressureKpa = MAX_VACUUM_TARGET_KPA;
    Serial.println("TARGET clamped to -90.00 kPa");
  }

  resetPid();
  state = ControllerState::REGULATING;
  phaseStartedMs = millis();
  updateIndicators();
  Serial.print("TARGET set to ");
  Serial.print(targetPressureKpa, 2);
  Serial.println(" kPa");
}

bool parseFloatToken(const char *token, float &value) {
  if (token == nullptr) {
    return false;
  }

  char *end = nullptr;
  value = strtof(token, &end);
  return end != token && end != nullptr && *end == '\0' && isfinite(value);
}

void commandError(const char *message) {
  if (controlMode == ControlMode::SERIAL_CONTROL) {
    stopAndVent(message);
  } else {
    Serial.println(message);
  }
}

void handleTuningCommand(const char *name, const char *argument, const char *extra) {
  float value = 0.0f;
  if (argument == nullptr || extra != nullptr || !parseFloatToken(argument, value)) {
    commandError("ERROR: malformed tuning command; venting");
    return;
  }

  Tuning candidate = tuning;
  if (strcasecmp(name, "KP") == 0) {
    candidate.kp = value;
  } else if (strcasecmp(name, "KI") == 0) {
    candidate.ki = value;
  } else if (strcasecmp(name, "KD") == 0) {
    candidate.kd = value;
  } else if (strcasecmp(name, "BAND") == 0) {
    candidate.bandKpa = value;
  } else {
    commandError("ERROR: unknown command; venting");
    return;
  }

  if (!tuningIsValid(candidate)) {
    commandError("ERROR: tuning value is outside its safe range; venting");
    return;
  }

  tuning = candidate;
  resetPid();
  Serial.print(name);
  Serial.println(" updated in RAM; send SAVE to persist");
}

void processCommand(char *line) {
  while (*line == ' ' || *line == '\t') {
    ++line;
  }
  char *tail = line + strlen(line);
  while (tail > line && (tail[-1] == ' ' || tail[-1] == '\t')) {
    *--tail = '\0';
  }
  if (*line == '\0') {
    return;
  }

  float numericTarget = 0.0f;
  if (parseFloatToken(line, numericTarget)) {
    setTarget(numericTarget);
    return;
  }

  char *savePointer = nullptr;
  char *command = strtok_r(line, " \t", &savePointer);
  char *argument = strtok_r(nullptr, " \t", &savePointer);
  char *extra = strtok_r(nullptr, " \t", &savePointer);

  if (strcasecmp(command, "ZERO") == 0 && argument == nullptr) {
    startZeroCalibration();
  } else if (strcasecmp(command, "STATUS") == 0 && argument == nullptr) {
    reportStatus();
  } else if (strcasecmp(command, "STATUS_STREAM") == 0 && argument == nullptr) {
    statusStreamEnabled = !statusStreamEnabled;
    Serial.print("STATUS stream ");
    Serial.println(statusStreamEnabled ? "enabled" : "disabled");
  } else if (strcasecmp(command, "SAVE") == 0 && argument == nullptr) {
    Serial.println(saveTuning() ? "Tuning saved" : "ERROR: tuning could not be saved");
  } else if (strcasecmp(command, "DEFAULTS") == 0 && argument == nullptr) {
    tuning = DEFAULT_TUNING;
    resetPid();
    Serial.println("Safe defaults loaded in RAM; send SAVE to persist");
  } else if (strcasecmp(command, "KP") == 0 || strcasecmp(command, "KI") == 0 ||
             strcasecmp(command, "KD") == 0 || strcasecmp(command, "BAND") == 0) {
    handleTuningCommand(command, argument, extra);
  } else {
    commandError("ERROR: malformed command; venting");
  }
}

void serviceSerial() {
  while (Serial.available() > 0) {
    const char character = static_cast<char>(Serial.read());
    if (character == '\r') {
      continue;
    }
    if (character == '\n') {
      serialLine[serialLength] = '\0';
      processCommand(serialLine);
      serialLength = 0;
      continue;
    }
    if (serialLength >= sizeof(serialLine) - 1) {
      serialLength = 0;
      commandError("ERROR: command too long; venting");
      continue;
    }
    serialLine[serialLength++] = character;
  }
}

void updateCalibration(uint32_t now) {
  setOutputs(PWM_OFF, false);
  if (state == ControllerState::CALIBRATING_SETTLE) {
    if (now - phaseStartedMs >= ZERO_SETTLE_MS) {
      zeroSum = 0.0f;
      zeroSumSquared = 0.0f;
      zeroSamples = 0;
      state = ControllerState::CALIBRATING_SAMPLE;
      Serial.println("ZERO: sampling");
    }
    return;
  }

  zeroSum += measuredVolts;
  zeroSumSquared += measuredVolts * measuredVolts;
  ++zeroSamples;
  if (zeroSamples < ZERO_SAMPLE_COUNT) {
    return;
  }

  const float average = zeroSum / zeroSamples;
  const float variance = fmaxf(0.0f, (zeroSumSquared / zeroSamples) - average * average);
  const float stddevKpa = sqrtf(variance) * SENSOR_KPA_PER_VOLT;
  if (stddevKpa > ZERO_MAX_STDDEV_KPA) {
    zeroCalibrated = false;
    state = ControllerState::IDLE;
    setOutputs(PWM_OFF, false);
    Serial.print("ERROR: ZERO unstable (stddev ");
    Serial.print(stddevKpa, 3);
    Serial.println(" kPa); vent and try again");
    return;
  }

  zeroVolts = average;
  measuredPressureKpa = 0.0f;
  zeroCalibrated = true;
  state = ControllerState::IDLE;
  setOutputs(PWM_OFF, false);
  Serial.print("ZERO complete: ");
  Serial.print(zeroVolts, 4);
  Serial.println(" V = 0.00 kPa");
}

void updateRegulation(uint32_t now) {
  const float measuredVacuumKpa = -measuredPressureKpa;
  const float targetVacuumKpa = -targetPressureKpa;
  const float errorKpa = targetVacuumKpa - measuredVacuumKpa;

  // Do not use the full-flow atmosphere vent as a fine pressure actuator.
  // At or beyond the target, turn the pump off but retain the pump-to-gripper
  // path. This avoids a 50 ms minimum passive-vent pulse while still allowing
  // normal leakage to bring an overshoot back toward the target.
  if (errorKpa <= tuning.bandKpa) {
    if (errorKpa < -tuning.bandKpa) {
      // An overshoot must not leave integral drive queued for the next cycle.
      resetPid();
    } else {
      integralTerm *= 0.98f;
      previousVacuumKpa = measuredVacuumKpa;
      filteredVacuumRate = 0.0f;
      lastPidMs = now;
    }
    setOutputs(PWM_OFF, true);
    return;
  }

  float dtSeconds = CONTROL_PERIOD_MS / 1000.0f;
  if (lastPidMs != 0) {
    dtSeconds = fmaxf(0.001f, (now - lastPidMs) / 1000.0f);
  }
  lastPidMs = now;

  float vacuumRate = 0.0f;
  if (isfinite(previousVacuumKpa)) {
    vacuumRate = (measuredVacuumKpa - previousVacuumKpa) / dtSeconds;
  }
  previousVacuumKpa = measuredVacuumKpa;
  filteredVacuumRate += DERIVATIVE_FILTER_ALPHA * (vacuumRate - filteredVacuumRate);

  integralTerm += errorKpa * dtSeconds;
  integralTerm = constrain(integralTerm, -PWM_MAX / fmaxf(tuning.ki, 0.001f),
                           PWM_MAX / fmaxf(tuning.ki, 0.001f));

  const float requestedPwm = tuning.kp * errorKpa + tuning.ki * integralTerm - tuning.kd * filteredVacuumRate;
  uint8_t desiredPwm = requestedPwm <= 0.0f ? PWM_OFF : static_cast<uint8_t>(constrain(requestedPwm, 0.0f, static_cast<float>(PWM_MAX)));

  if (desiredPwm > pumpPwm + PWM_SLEW_PER_CYCLE) {
    desiredPwm = pumpPwm + PWM_SLEW_PER_CYCLE;
  } else if (pumpPwm > desiredPwm + PWM_SLEW_PER_CYCLE) {
    desiredPwm = pumpPwm - PWM_SLEW_PER_CYCLE;
  }

  setOutputs(desiredPwm, true);
}

void updateController(uint32_t now) {
  if (!adsAvailable || state == ControllerState::FAULT) {
    return;
  }

  float volts = NAN;
  if (!readAveragedVoltage(volts) || volts < ADC_MIN_VALID_VOLTS || volts > ADC_MAX_VALID_VOLTS) {
    // A questionable sensor value must never leave the previous pump command active.
    setOutputs(PWM_OFF, false);
    resetPid();
    ++invalidReadings;
    if (invalidReadings >= MAX_INVALID_READINGS) {
      enterFault("pressure signal outside 0.25..4.75 V");
    }
    return;
  }

  invalidReadings = 0;
  measuredVolts = volts;
  measuredPressureKpa = zeroCalibrated ? SENSOR_KPA_PER_VOLT * (measuredVolts - zeroVolts) : NAN;

  if (state == ControllerState::CALIBRATING_SETTLE || state == ControllerState::CALIBRATING_SAMPLE) {
    updateCalibration(now);
  } else if (state == ControllerState::REGULATING) {
    updateRegulation(now);
  } else {
    setOutputs(PWM_OFF, false);
  }
}

void setup() {
  Serial.begin(115200);

  pinMode(PIN_PWM_PUMP, OUTPUT);
  pinMode(PIN_PWM_VALVE, OUTPUT);
  pinMode(PIN_LED_TARGET_REACHED, OUTPUT);
  pinMode(PIN_LED_ACTIVE, OUTPUT);
  pinMode(PIN_SWITCH_MANUAL_FULL, INPUT);
  pinMode(PIN_SWITCH_SERIAL, INPUT);
  setOutputs(PWM_OFF, false);

  Wire.begin(PIN_I2C_SDA, PIN_I2C_SCL);
  adsAvailable = initializeAds1115();
  if (!adsAvailable) {
    enterFault(ALLOW_FLOATING_ADS1115_ADDR_FOR_TESTING
                   ? "ADS1115 not found at 0x48..0x4B; verify I2C wiring"
                   : "ADS1115 not found at 0x48; verify ADDR is tied to GND and I2C wiring");
    return;
  }

  ads.setGain(GAIN_TWOTHIRDS);
  ads.setDataRate(RATE_ADS1115_250SPS);
  loadTuning();
  if (adsAddressInUse != ADS1115_GND_ADDRESS) {
    Serial.print("WARNING: using floating-ADDR test override at 0x");
    Serial.println(adsAddressInUse, HEX);
  }
  Serial.println("Vacuum controller ready. Run ZERO with the port vented, then send a negative kPa target.");
}

void loop() {
  serviceControlMode();
  serviceSerial();

  const uint32_t now = millis();
  if (controlMode == ControlMode::SERIAL_CONTROL && now - lastControlMs >= CONTROL_PERIOD_MS) {
    lastControlMs = now;
    updateController(now);
  }

  if (statusStreamEnabled && now - lastStatusStreamMs >= STATUS_STREAM_PERIOD_MS) {
    lastStatusStreamMs = now;
    reportStatus();
  }
}

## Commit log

2026-09-16 Update .gitignore to include KiCAD backup and lock files
2026-09-16 Add KiCAD board project.
    [electropneu.kicad_pcb, electropneu.kicad_sch, electropneu.step]
2026-09-16 Update README and schematic for pneumatic control board; add control mode logic and LED indicators in firmware
    [electropneu.kicad_sch]
2026-09-18 Refactor README to improve clarity on ADS1115 address configuration and installation steps; consolidate mode switch behavior section

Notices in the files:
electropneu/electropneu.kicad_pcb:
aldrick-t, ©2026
